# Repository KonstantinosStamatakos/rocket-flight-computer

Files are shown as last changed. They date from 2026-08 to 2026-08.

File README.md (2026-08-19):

# Rocket Flight Computer

A custom STM32F405-based flight computer designed and built for my Level 2 high-power rocket.

The system integrates an IMU, barometer, GPS receiver, microSD storage, and USB interface on a custom PCB. I developed the embedded firmware in C for sensor acquisition, calibration, data logging, and real-time estimation of altitude and vertical velocity.

The flight computer has completed integrated ground testing and is currently being prepared for its first flight.

<p align="center">
  
</p>

---

## Hardware Design

The flight computer is built around an STM32F405 microcontroller. I designed the board to integrate the sensing, storage, and communication hardware required for flight onto a single PCB rather than using separate development boards.

The main hardware includes:

- STM32F405 microcontroller
- BMP581 barometer
- LSM6DSO32 accelerometer and gyroscope
- GPS receiver
- microSD card
- USB interface

The BMP581 and LSM6DSO32 communicate with the STM32 over I²C, the GPS receiver uses UART, and flight data is written to the microSD card through SDIO.

### Schematic

<p align="center">
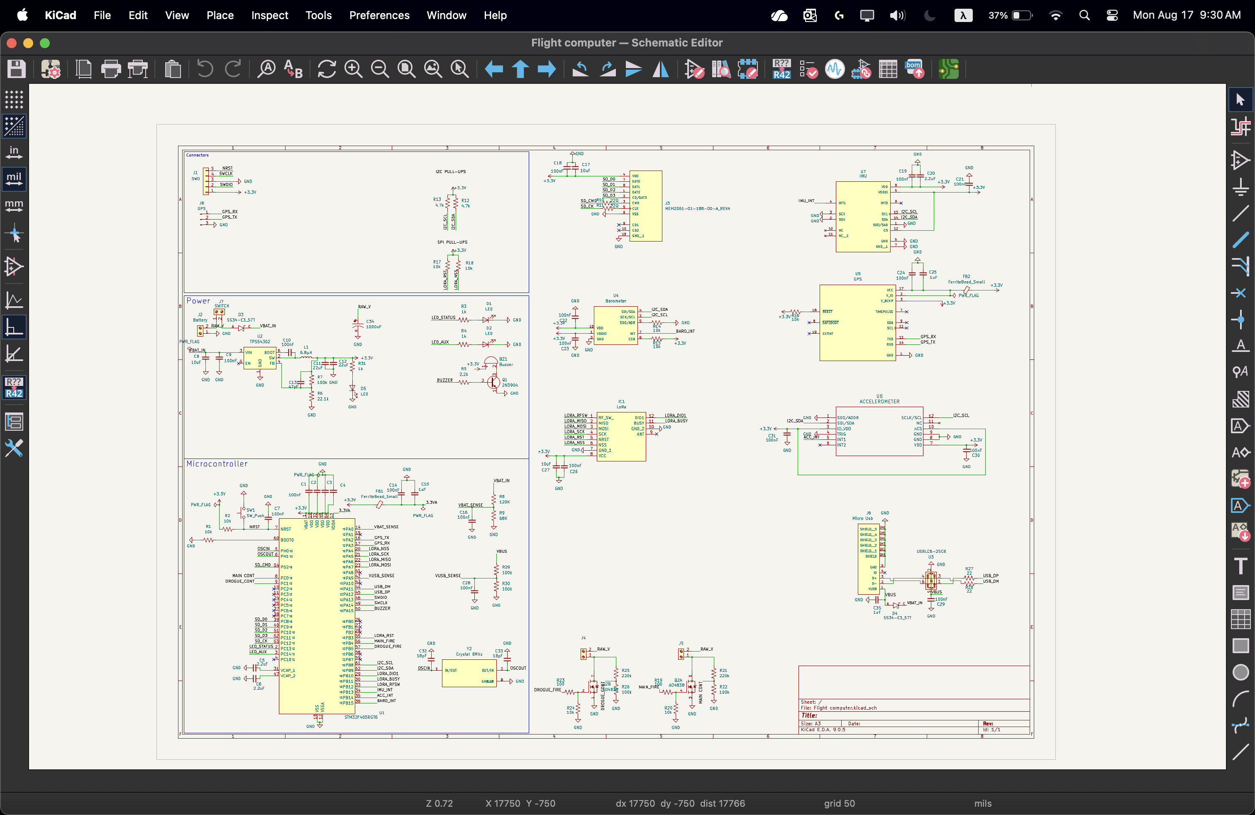
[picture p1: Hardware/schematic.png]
  
</p>

### PCB Layout

<p align="center">
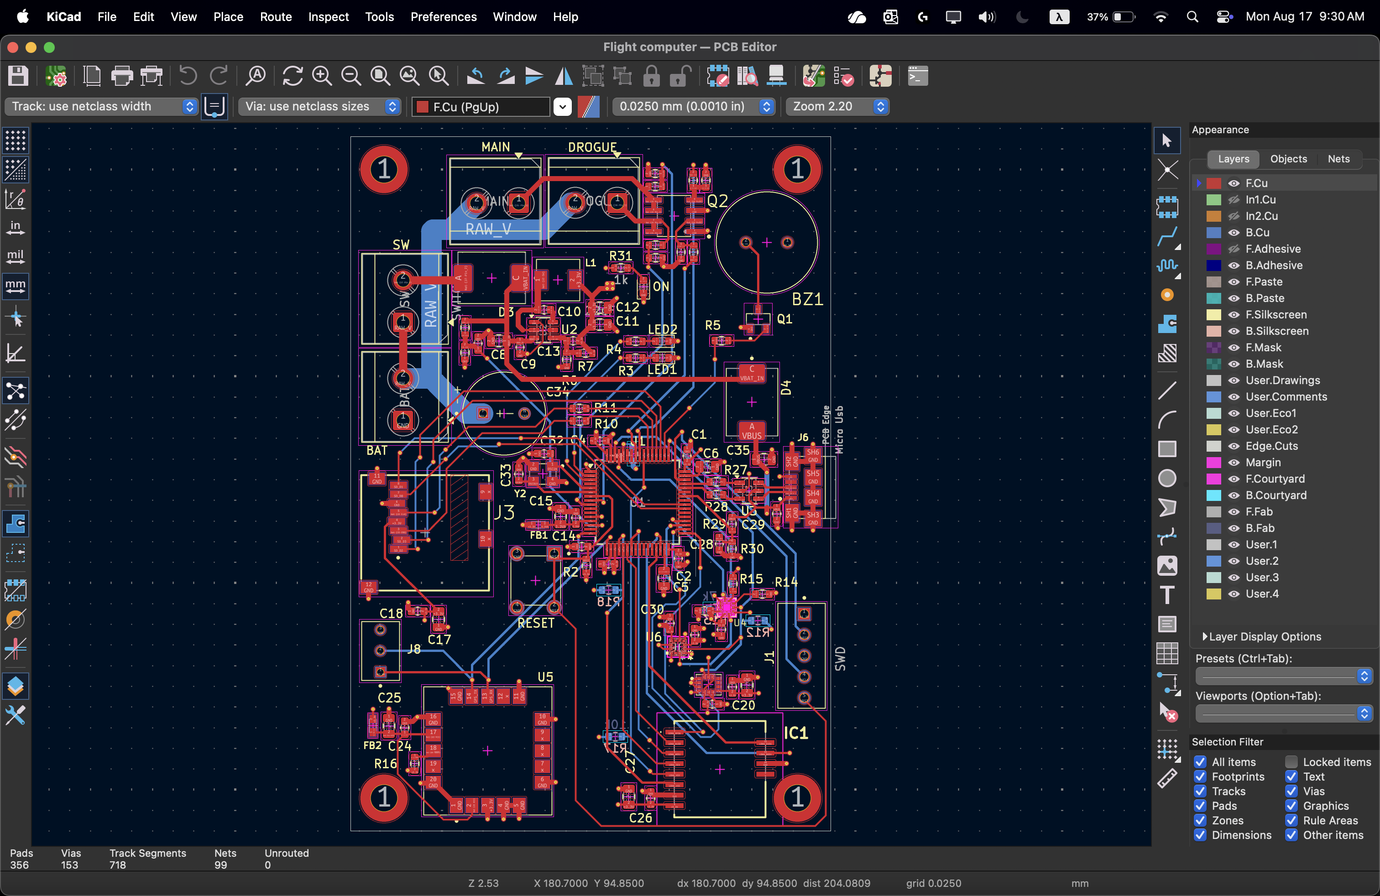
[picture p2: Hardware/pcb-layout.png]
  
</p>

---

## Firmware

The firmware is written in C and organized into separate modules for the major subsystems:

```text
bmp581.c / bmp581.h
imu.c / imu.h
gps.c / gps.h
sd_logger.c / sd_logger.h
vertical_filter.c / vertical_filter.h
```

I developed the code for sensor acquisition, GPS communication, microSD logging, USB debugging, calibration, and vertical-state estimation.

The main application continuously reads the onboard sensors, updates the altitude and vertical-velocity estimate, records the data to the microSD card, and provides live output over USB during testing.

---

## State Estimation

The flight computer estimates the rocket's altitude and vertical velocity in real time using data from the barometer and accelerometer.

Barometric altitude provides an absolute measurement of altitude, but it contains measurement noise. Accelerometer data responds much faster to changes in motion, but integrating acceleration causes errors to accumulate over time.

To combine the advantages of both measurements, I implemented a linear Kalman filter.

The estimator tracks two states:

```text
altitude
vertical velocity
```

Acceleration is used during the prediction step to estimate how the rocket's vertical state changes between measurements. Barometric altitude is then used to correct the estimate.

This allows the flight computer to maintain a continuous estimate of the rocket's vertical motion without relying entirely on either sensor.

---

## Data Logging

Flight data is recorded to an onboard microSD card in CSV format using the STM32 SDIO interface and FatFs.

The logs contain raw sensor measurements together with the estimated altitude and vertical velocity, allowing the flight to be analyzed after recovery.

---

## Hardware and Firmware Bring-Up

A significant part of the project involved debugging the interaction between the custom PCB and the embedded firmware.

I brought up the system incrementally, testing individual subsystems before running the complete flight software.

This included:

- verifying communication with the BMP581 and LSM6DSO32
- configuring and testing the GPS UART interface
- calibrating sensor measurements
- bringing up USB CDC for live debugging
- initializing the microSD card through SDIO
- creating and writing files using FatFs
- validating continuous CSV logging
- integrating the vertical-state estimator with the sensor pipeline

The microSD interface was one of the more challenging parts of the bring-up. Debugging required checking both the physical SDIO connections and the STM32 configuration before reliable file creation and continuous logging were achieved.

Once the individual subsystems were working independently, I integrated them into the complete flight-computer firmware and tested them simultaneously.

---

## Current Status

The flight computer is operational in ground testing.

The custom PCB, sensor acquisition, GPS communication, USB debugging, microSD logging, and vertical-state estimator have been integrated and tested together.

The next major step is to fly the system onboard my Level 2 rocket.

Data recorded during the first flight will be used to evaluate the altitude and vertical-velocity estimates under real flight conditions and tune the estimator for future launches.

---

## Tools and Technologies

**Hardware:** STM32F405, BMP581, LSM6DSO32, GPS, microSD

**Firmware:** C, STM32 HAL, FatFs

**Interfaces:** I²C, UART, SDIO, USB CDC

**Analysis:** Python

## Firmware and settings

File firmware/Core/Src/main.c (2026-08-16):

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
/* Includes ------------------------------------------------------------------*/
#include "main.h"
#include "usb_device.h"
#include "usbd_cdc_if.h"
#include "flight_app.h"
#include <stdio.h>
#include "fatfs.h"

I2C_HandleTypeDef hi2c1;

SD_HandleTypeDef hsd;

UART_HandleTypeDef huart2;

void SystemClock_Config(void);
static void MX_GPIO_Init(void);
static void MX_I2C1_Init(void);
static void MX_USART2_UART_Init(void);
static void MX_SDIO_SD_Init(void);
/* USER CODE BEGIN 0 */
int _write(int file, char *ptr, int len)
{
    uint32_t start = HAL_GetTick();

    while (CDC_Transmit_FS((uint8_t *)ptr, len) == USBD_BUSY)
    {
        if ((HAL_GetTick() - start) > 20U)
        {
            /* Drop message if USB is busy too long */
            return len;
        }
    }
    return len;
}

/* USER CODE END 0 */

/**
  * @brief  The application entry point.
  * @retval int
  */
int main(void)
{

  /* MCU Configuration--------------------------------------------------------*/

  /* Reset of all peripherals, Initializes the Flash interface and the Systick. */
  HAL_Init();

  /* Configure the system clock */
  SystemClock_Config();

  /* Initialize all configured peripherals */
  MX_GPIO_Init();
  MX_USB_DEVICE_Init();
  MX_I2C1_Init();
  MX_USART2_UART_Init();
  MX_SDIO_SD_Init();
  MX_FATFS_Init();
  /* USER CODE BEGIN 2 */
  HAL_Delay(2000);

  printf("Booting flight project...\r\n");

  /* Start application layer */
  FlightApp_Init();
  /* USER CODE END 2 */

  /* Infinite loop */
  /* USER CODE BEGIN WHILE */
  while (1)
  {
    /* USER CODE END WHILE */
	  FlightApp_Run();
    /* USER CODE BEGIN 3 */
  }
  /* USER CODE END 3 */
}

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


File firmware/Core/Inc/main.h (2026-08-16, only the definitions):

#define LED_STATUS_Pin GPIO_PIN_13
#define LED_STATUS_GPIO_Port GPIOC
#define Buzzer_Pin GPIO_PIN_15
#define Buzzer_GPIO_Port GPIOA

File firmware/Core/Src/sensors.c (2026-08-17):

#include "sensors.h"
#include "app_config.h"
#include "bmp581.h"

#include <math.h>
#include <string.h>

/*
 * ============================================================
 * DRIVER INSTANCES
 * ============================================================
 */

static BMP581_t bmp581;
static LSM6DSO32_t imu_device;

static SensorsData_t sensors;

static UART_HandleTypeDef *gps_uart = NULL;

static uint8_t gps_rx_byte = 0U;

/*
 * ============================================================
 * BAROMETER STATE
 * ============================================================
 */

static float startup_pressure_hpa = 0.0f;
static float filtered_pressure_hpa = 0.0f;

static uint8_t altitude_zero_ready = 0U;
static uint8_t pressure_filter_ready = 0U;

/*
 * ============================================================
 * PRESSURE TO RELATIVE ALTITUDE
 * ============================================================
 */

static float Sensors_CalculateRelativeAltitude(float pressure_hpa,
                                               float reference_hpa)
{
    if (pressure_hpa <= 0.0f || reference_hpa <= 0.0f)
    {
        return 0.0f;
    }

    return 44330.0f *
           (1.0f - powf(pressure_hpa / reference_hpa, 0.1903f));
}

/*
 * ============================================================
 * SENSORS INITIALIZATION
 * ============================================================
 */

uint8_t Sensors_Init(I2C_HandleTypeDef *hi2c,
                     UART_HandleTypeDef *huart)
{
    memset(&sensors, 0, sizeof(sensors));

    /*
     * ---------------- BMP581 ----------------
     */

    sensors.bmp_ok =
        BMP581_Init(&bmp581,
                    hi2c,
                    BMP581_I2C_ADDR);

    /*
     * ---------------- LSM6DSO32 ----------------
     */

    sensors.imu_ok =
        LSM6DSO32_Init(&imu_device,
                       hi2c,
                       LSM6DSO32_I2C_ADDR);

    /*
     * ---------------- GPS ----------------
     */

    gps_uart = huart;

    GPS_Init(&sensors.gps, huart);

    sensors.gps_ok = 1U;

    if (HAL_UART_Receive_IT(gps_uart,
                           &gps_rx_byte,
                           1U) != HAL_OK)
    {
        sensors.gps_ok = 0U;
    }

    /*
     * ========================================================
     * BAROMETER STARTUP CALIBRATION
     * ========================================================
     */

    if (sensors.bmp_ok)
    {
        float pressure_sum_hpa = 0.0f;
        uint32_t valid_samples = 0U;

        HAL_Delay(1000U);

        for (uint32_t i = 0U; i < 50U; i++)
        {
            float temperature_c = 0.0f;
            float pressure_pa = 0.0f;

            if (BMP581_ReadTempPressure(&bmp581,
                                        &temperature_c,
                                        &pressure_pa))
            {
                pressure_sum_hpa += pressure_pa / 100.0f;
                valid_samples++;
            }

            HAL_Delay(20U);
        }

        if (valid_samples > 0U)
        {
            startup_pressure_hpa =
                pressure_sum_hpa / (float)valid_samples;

            filtered_pressure_hpa = startup_pressure_hpa;

            altitude_zero_ready = 1U;
            pressure_filter_ready = 1U;
        }
        else
        {
            sensors.bmp_ok = 0U;
        }
    }
  
    return (sensors.bmp_ok && sensors.imu_ok) ? 1U : 0U;
}

/*
 * ============================================================
 * IMU UPDATE
 * ============================================================
 */

uint8_t Sensors_UpdateImu(void)
{
    if (!sensors.imu_ok)
    {
        return 0U;
    }

    if (!LSM6DSO32_ReadAll(&imu_device,
                           &sensors.imu))
    {
        sensors.imu_new_data = 0U;
        return 0U;
    }

    sensors.imu_timestamp_ms = HAL_GetTick();
    sensors.imu_new_data = 1U;

    return 1U;
}

/*
 * ============================================================
 * BAROMETER UPDATE
 * ============================================================
 */

uint8_t Sensors_UpdateBaro(void)
{
    float temperature_c = 0.0f;
    float pressure_pa = 0.0f;

    if (!sensors.bmp_ok)
    {
        return 0U;
    }

    if (!BMP581_ReadTempPressure(&bmp581,
                                 &temperature_c,
                                 &pressure_pa))
    {
        sensors.baro_new_data = 0U;
        return 0U;
    }

    sensors.bmp_temp_c = temperature_c;
    sensors.pressure_pa = pressure_pa;
    sensors.pressure_hpa = pressure_pa / 100.0f;

    if (!pressure_filter_ready)
    {
        filtered_pressure_hpa = sensors.pressure_hpa;
        pressure_filter_ready = 1U;
    }
    else
    {
        filtered_pressure_hpa =
            ((1.0f - BARO_FILTER_ALPHA) *
             filtered_pressure_hpa)
            +
            (BARO_FILTER_ALPHA *
             sensors.pressure_hpa);
    }

    if (altitude_zero_ready)
    {
        sensors.baro_altitude_m =
            Sensors_CalculateRelativeAltitude(
                filtered_pressure_hpa,
                startup_pressure_hpa);
    }
    else
    {
        sensors.baro_altitude_m = 0.0f;
    }

    sensors.baro_timestamp_ms = HAL_GetTick();
    sensors.baro_new_data = 1U;

    return 1U;
}

/*
 * ============================================================
 * GPS UART INTERRUPT HANDLING
 * ============================================================
 */

void Sensors_GpsRxComplete(UART_HandleTypeDef *huart)
{

    if (huart != gps_uart)
    {
        return;
    }

    GPS_ProcessByte(&sensors.gps, gps_rx_byte);

    if (sensors.gps.sentence_ready)
    {
        if (GPS_ParseLatest(&sensors.gps))
        {
            sensors.gps_timestamp_ms = HAL_GetTick();
            sensors.gps_new_data = 1U;
        }

        sensors.gps.sentence_ready = 0U;
    }
    HAL_UART_Receive_IT(gps_uart,
                        &gps_rx_byte,
                        1U);
}


SensorsData_t *Sensors_GetData(void)
{
    return &sensors;
}

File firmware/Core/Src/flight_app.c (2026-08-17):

#include "flight_app.h"
#include "app_config.h"
#include "sensors.h"
#include "vertical_filter.h"
#include "main.h"
#include "sd_logger.h"

#include <stdio.h>
#include <stdint.h>

extern I2C_HandleTypeDef hi2c1;
extern UART_HandleTypeDef huart2;

/*
 * ============================================================
 * APPLICATION TIMERS
 * ============================================================
 */

static uint32_t last_imu_ms = 0U;
static uint32_t last_baro_ms = 0U;
static uint32_t last_filter_ms = 0U;
static uint32_t last_debug_ms = 0U;
static uint32_t last_sd_log_ms = 0U;
static uint32_t last_sd_sync_ms = 0U;


static VerticalFilter_t vertical_filter;

static float accel_z_rest_g = 1.0f;

static void FlightApp_CalibrateAccelerometer(void)
{
    float sum_z_g = 0.0f;
    uint32_t valid_samples = 0U;

    printf("Keep the board still for accelerometer calibration...\r\n");

    for (uint32_t i = 0U; i < 200U; i++)
    {
        if (Sensors_UpdateImu())
        {
            SensorsData_t *s = Sensors_GetData();

            sum_z_g += s->imu.acc_z_g;
            valid_samples++;
        }

        HAL_Delay(5U);
    }

    if (valid_samples > 0U)
    {
        accel_z_rest_g =
            sum_z_g / (float)valid_samples;
    }
    else
    {
        accel_z_rest_g = 1.0f;
    }

    printf("Accelerometer Z rest value = %.5f g\r\n",
           accel_z_rest_g);
}

/*
 * ============================================================
 * FLIGHT APPLICATION INITIALIZATION
 * ============================================================
 */

void FlightApp_Init(void)
{
    uint8_t sensors_ok;
    
    sensors_ok = Sensors_Init(&hi2c1, &huart2);

    printf("Sensor initialization status = %u\r\n",
           sensors_ok);

    FlightApp_CalibrateAccelerometer();

    VerticalFilter_Init(&vertical_filter,
                        0.0f,
                        0.0f,
                        25.0f,
                        4.0f);

    SDLoggerStatus_t sd_status = SDLogger_Init();

    if (sd_status == SD_LOGGER_OK)
    {
        printf("SD logger started\r\n");
        printf("Log file: %s\r\n", SDLogger_GetFilename());
    }
    else
    {
        printf("SD logger initialization failed: %u\r\n",
               (unsigned int)sd_status);
    }

    uint32_t now = HAL_GetTick();

    last_imu_ms = now;
    last_baro_ms = now;
    last_filter_ms = now;
    last_debug_ms = now;
    last_sd_log_ms = now;
    last_sd_sync_ms = now;

    printf("Flight application started\r\n");
}

/*
 * ============================================================
 * MAIN NON-BLOCKING APPLICATION FUNCTION
 * ============================================================
 */

void FlightApp_Run(void)
{
    uint32_t now = HAL_GetTick();

    SensorsData_t *s = Sensors_GetData();

    /*
     * ========================================================
     * IMU TASK — 200 Hz
     * ========================================================
     */

    if ((uint32_t)(now - last_imu_ms) >= IMU_PERIOD_MS)
    {
        last_imu_ms += IMU_PERIOD_MS;

        Sensors_UpdateImu();
    }

    /*
     * ========================================================
     * BAROMETER TASK — 50 Hz
     * ========================================================
     */

    if ((uint32_t)(now - last_baro_ms) >= BARO_PERIOD_MS)
    {
        last_baro_ms += BARO_PERIOD_MS;

        Sensors_UpdateBaro();
    }

    /*
     * ========================================================
     * VERTICAL FILTER TASK — 200 Hz
     * ========================================================
     */

    if ((uint32_t)(now - last_filter_ms) >= FILTER_PERIOD_MS)
    {
        uint32_t elapsed_ms =
            (uint32_t)(now - last_filter_ms);

        float dt_s = (float)elapsed_ms * 0.001f;

        last_filter_ms = now;

        if (s->imu_ok && dt_s > 0.0f && dt_s < 0.050f)
        {
            float accel_z_mps2 =
                (s->imu.acc_z_g - accel_z_rest_g)
                * GRAVITY_MPS2;

            if (accel_z_mps2 > -ACCEL_DEADBAND_MPS2 &&
                accel_z_mps2 <  ACCEL_DEADBAND_MPS2)
            {
                accel_z_mps2 = 0.0f;
            }

            VerticalFilter_Predict(&vertical_filter,
                                   accel_z_mps2,
                                   dt_s);
        }

        if (s->bmp_ok && s->baro_new_data)
        {
            VerticalFilter_UpdateBaro(
                &vertical_filter,
                s->baro_altitude_m);

            s->baro_new_data = 0U;
        }
    }

    /*
     * ============================================================
     * SD LOGGING TASK — 50 Hz
     * ============================================================
     */

    if ((uint32_t)(now - last_sd_log_ms) >= SD_LOG_PERIOD_MS)
    {
        last_sd_log_ms = now;

        if (SDLogger_IsReady())
        {
            SDLogRecord_t record;

            record.timestamp_ms = now;

            record.pressure_pa =
                s->pressure_pa;

            record.baro_altitude_m =
                s->baro_altitude_m;
            
            record.estimated_altitude_m =
                VerticalFilter_GetAltitude(&vertical_filter);

            record.estimated_velocity_mps =
                VerticalFilter_GetVelocity(&vertical_filter);
            
            record.accel_x_g = s->imu.acc_x_g;
            record.accel_y_g = s->imu.acc_y_g;
            record.accel_z_g = s->imu.acc_z_g;

            record.gyro_x_dps = s->imu.gyro_x_dps;
            record.gyro_y_dps = s->imu.gyro_y_dps;
            record.gyro_z_dps = s->imu.gyro_z_dps;

            record.gps_fix =
                s->gps.valid_fix;

            record.gps_satellites =
                s->gps.satellites;

            record.gps_latitude_deg =
                s->gps.latitude_deg;

            record.gps_longitude_deg =
                s->gps.longitude_deg;

            record.gps_altitude_m =
                s->gps.altitude_m;

            SDLoggerStatus_t status =
                SDLogger_WriteRecord(&record);

            if (status != SD_LOGGER_OK)
            {
                printf("SD write error: %u\r\n",
                       (unsigned int)status);
            }
        }
    }

    /*
     * ============================================================
     * SD SYNC TASK — 1 Hz
     * ============================================================
     */

    if ((uint32_t)(now - last_sd_sync_ms) >= SD_SYNC_PERIOD_MS)
    {
    	last_sd_sync_ms = now;

        if (SDLogger_IsReady())
        {
            SDLoggerStatus_t status = SDLogger_Sync();

            if (status != SD_LOGGER_OK)
            {
                printf("SD sync error: %u\r\n",
                       (unsigned int)status);
            }
        }
    }
    /*
     * ========================================================
     * USB DEBUG TASK — 2 Hz
     * ========================================================
     */
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

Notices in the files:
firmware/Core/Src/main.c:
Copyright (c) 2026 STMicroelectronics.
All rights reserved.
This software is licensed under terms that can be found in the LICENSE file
